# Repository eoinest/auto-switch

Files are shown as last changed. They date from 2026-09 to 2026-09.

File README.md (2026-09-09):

# auto-switch

A small Wi-Fi actuator that presses an existing **Decora-style paddle light switch**, using one MG90S servo and a 3D-printed mount.

The current POC uses a **headerless ESP32-S2 Mini** running MicroPython. It hosts a minimal website with **On**, **Off**, and **Recalibrate** buttons. Center calibration uses small movement controls and saves with **Done**. Open **http://auto-switch.local/** from a phone on the same Wi-Fi. The Mac is only needed for programming; it does not host the switch website.

## What works today

The USB-powered S2 joins Wi-Fi and serves the website directly. Both buttons render on a phone. Servo movement is still disabled pending wiring and calibration.

| Part of the POC | Status |
|---|---|
| ESP32-hosted website and local hostname | Tested on the board and phone |
| One MG90S servo operating the bedroom switch | Wiring, calibration and physical operation pending |
| Four AA batteries with a 5 V buck-boost converter | Selected; battery circuit and runtime untested |
| Printed servo mount and paddle | STL exported; physical fit and attachment unverified |
| Separate electronics holder | Screw mounts and retaining jaws modeled; converter measurements and dry fit pending |

## Build this version

**[Download the USB setup app for Mac](https://github.com/eoinest/auto-switch/releases/tag/companion-v0.1.0)** — Apple Silicon, macOS 15+, preview build. Python and USB tools included.

1. **[Parts list](BOM.md)** — selected components and what is already available.
2. **[Solder pads and wiring](docs/solder-prep.md)** — three S2 pads, four converter terminal groups and one servo. [Latest three-critic sanity check](docs/reviews/wiring-decision-2026-09-08.md); [detailed breadboard map](docs/s2-aa-poc.md).
3. **[Firmware](docs/s2-firmware.md)** — install MicroPython files, enter Wi-Fi credentials privately and open the phone page.
   **[Wireless updates](docs/wireless-updates.md)** — hold BOOT/0 for browser updates on home Wi-Fi; no recovery access point. [USB setup companion](docs/usb-wifi-setup.md) saves Wi-Fi credentials. Board verification pending.
4. **[Servo mechanism](docs/servo-command-mount.md)** — approved export, stock horn and two narrow Command-strip mounting pads.
5. **[Electronics holder](docs/electronics-retention.md)** — mounting-hole fastenings, converter clamps and removable battery retention under review.

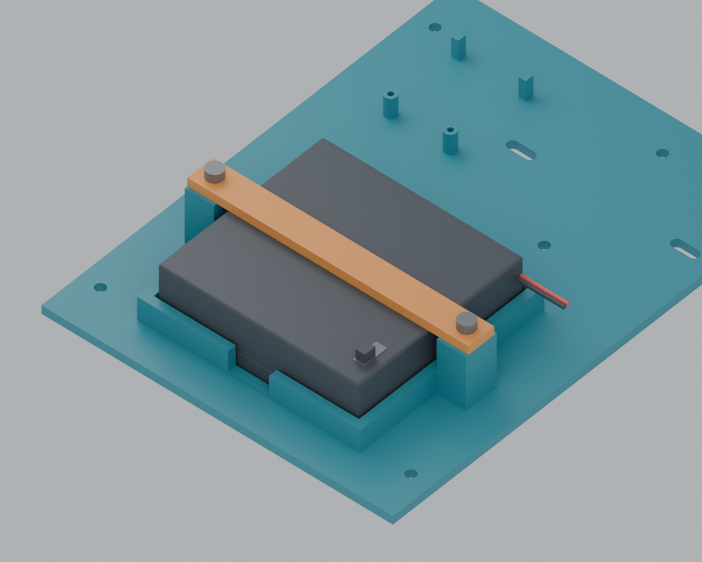
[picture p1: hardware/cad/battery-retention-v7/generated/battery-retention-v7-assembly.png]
Revised carrier with two centered battery towers and one flat bar


*The [v7 carrier and crossbar](hardware/cad/battery-retention-v7/README.md) use two centered towers level with the nominal battery case, with zero designed vertical gap. Reprint the carrier and bar; reuse the separate wall bracket. Physical fit is pending. The [converter clip audit](hardware/cad/battery-retention-v6/booster-fit-audit.md) identifies the unverified board thickness and dimensions.*

**Latest combined replacement print:** [V8 fit-test STL and instructions](hardware/cad/revision-print-v8/README.md) includes the revised battery carrier/bar and selected option C booster mount. Booster dimensions remain provisional; reuse the existing wall bracket.

## Double and triple switch concepts

[Multi-switch CAD](hardware/cad/servo-multi/README.md) extends the confirmed single-switch baseline with one servo per rocker, separate screw-on servo saddles, and two outer Command-strip pads. Each variant includes a Blender assembly and a master STL with the detached printed parts arranged on an A1 bed. The triple raises its center servo to clear its neighbor. These new mechanisms need physical motion testing; multi-servo electronics and firmware are separate future work.

## Power and control

Today, USB powers the ESP32. The planned portable version uses the holder's switch and a buck-boost converter to supply regulated **5 V to both the S2's VBUS pad and the servo**, with a shared ground. GPIO16 supplies the servo control signal.

The POC stays connected to Wi-Fi. It has no Daily/check-in selector, servo power gate or battery-level display. Each On/Off command briefly presses the requested end and returns to the calibrated neutral position so the rocker can be used by hand. Repeated commands still press; without a switch-position sensor, reported state stays unknown. Servo PWM stopping does not disconnect servo power.

For USB setup, open the dedicated booster-to-VBUS isolation switch, turn the battery holder off and unplug the servo connector; see the [USB setup and wiring map](docs/usb-wifi-setup.md). Before enabling movement, verify the converter output and calibrate the servo away from the wall switch. Keep private Wi-Fi configuration out of Git: [credential handling](docs/private-configuration.md).

## Project files

```text
firmware/                         MicroPython code and minimal switch website
hardware/cad/servo-command/        Isolated single-servo mechanism
hardware/cad/servo-multi/          Double/triple mechanical concepts and master STLs
hardware/cad/electronics-retention-v4/  Flat carrier, screw-on wall bracket and master STL
hardware/cad/battery-retention-v5/ Replacement battery rails, pressure pads and shims
hardware/cad/battery-retention-v6/ Archived upper-bar preview and booster clip fit audit
hardware/cad/battery-retention-v7/ Current carrier: two centered towers and one flat bar
hardware/wiring/s2-aa-poc/         Current bench wiring diagram
learn/s2-aa-poc.html               Interactive wiring viewer
```

See the [documentation index](docs/README.md) for source audits, development checks and historical designs. Earlier Pico, Mac gateway and battery-saving work remains in the repository as reference; it is not the current build guide.

Project-authored code, docs and original CAD use the [MIT license](LICENSE). Third-party reference CAD retains its [vendor terms](hardware/components/vendor/NOTICE.md).

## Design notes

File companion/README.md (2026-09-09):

# USB Wi-Fi setup

## Downloadable Mac app

[Download Auto Switch Setup 0.1.0](https://github.com/eoinest/auto-switch/releases/tag/companion-v0.1.0).
Unzip and double-click **Auto Switch Setup.app** (optionally drag it to Applications).
It opens the setup page in your default browser. Python and USB tools are included;
no terminal commands or dependency installation are needed. Use **Quit setup app**
on the page when finished. The app picks a free local port automatically.

This preview supports **Apple Silicon Macs, macOS 15 or later**. It is ad-hoc signed,
not Apple-notarized; macOS may block the first launch on a recipient's computer.
See [Apple's guidance on opening downloaded apps](https://support.apple.com/en-us/102445).
Do not disable system-wide security protections. Intel Macs and Windows are not
included in this release. Saving to a physical ESP32 still needs hardware testing.

The packaged app keeps temporary device settings under
`~/Library/Application Support/Auto Switch Setup/private/`, outside the app bundle,
with owner-only permissions, and deletes them after each setup attempt. The ZIP
contains no Wi-Fi passwords or device configuration. Firmware installation still
uses the project tooling; this companion only saves Wi-Fi on an already-configured board.

## Run from source

From the repository root:

```sh
python3 companion/server.py
```

Open **http://127.0.0.1:8790/** on this Mac. The companion uses the repository’s `.venv/bin/mpremote` when present, otherwise `python3 -m mpremote` (install with `python3 -m pip install mpremote`). Use `--port 8791` if needed. Stop with Ctrl-C.

Before connecting USB, turn **battery power OFF** and the **dedicated booster → ESP32 VBUS isolation switch OFF**, or physically disconnect that VBUS wire. Also unplug the servo’s three-wire connector; its control signal otherwise remains connected to an unpowered servo. Battery OFF alone leaves a possible USB backfeed path. Connect the already-provisioned S2 Mini using a USB data cable, select its port, enter the Wi-Fi network and password, and save. This does not install firmware. The device must already have a valid `config.json`. When finished, unplug USB first, then reconnect the servo and restore the battery circuit.

The companion reads the device configuration first, changes only `wifi.ssid` and `wifi.password`, uploads a temporary configuration, then renames it over `config.json` and restarts the board. Existing calibration and other configuration are preserved. Failed reads never create replacement defaults. If restart cannot be confirmed after saving, the page tells you to press RST.

The web server binds only to `127.0.0.1`. Host, Origin and random CSRF checks protect writes; credentials travel in the POST body, never URLs or process arguments. There are no HTTP access logs. Device-command output is captured and never displayed. Temporary configuration files live under ignored `.local/s2/` with owner-only directory/file permissions and are deleted after each attempt. A forced process kill or computer crash can leave a private temporary directory there; it remains ignored by Git. Close the page and stop the companion when finished.

Select a 2.4 GHz personal Wi-Fi network supported by the S2 Mini. Passwords must contain 8–63 printable ASCII characters. After restart, join that Wi-Fi on your phone and open `http://auto-switch.local/` or the device’s address. There is no fallback access point or Wi-Fi editor on the device in this workflow.

## Build the Mac app

On an Apple Silicon Mac with Python 3.14 (this release was built on macOS 15.7.4):

```sh
python3 -m venv /tmp/auto-switch-build
/tmp/auto-switch-build/bin/python -m pip install -r companion/packaging/requirements.txt
/tmp/auto-switch-build/bin/python companion/packaging/build_macos.py
python3 companion/packaging/verify_macos.py
```

The shareable ZIP and `SHA256SUMS.txt` appear under `dist/companion/`. The verifier
extracts the ZIP to a path with spaces, checks its signature/architecture and
private-file inventory, runs the bundled USB helper on a minimal PATH, then tests
the HTTP assets, port enumeration and authenticated Quit action. It does not write
to USB hardware. Build inputs explicitly include UI assets and dependency metadata,
not the repository's private configuration directories. Dependency licenses are
included in the application resources.

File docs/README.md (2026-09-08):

# Documentation

Start with the [project overview](../README.md). The current POC is one headerless ESP32-S2 Mini, one MG90S servo, and a planned four-AA/5 V buck-boost supply. The ESP32 hosts the On/Off website directly.

## Current build

| Guide | Use it for |
|---|---|
| [Parts list](../BOM.md) | Current components and purchase links |
| [S2 wiring](s2-aa-poc.md) | Breadboard connections and power checks |
| [S2 firmware](s2-firmware.md) | Wi-Fi setup, board-hosted website and updating files |
| [USB Wi-Fi companion and isolation switch](usb-wifi-setup.md) | Save credentials over USB and wire the dedicated VBUS switch |
| [Home Wi-Fi updates](wireless-updates.md) | Upload application bundles after connecting to home Wi-Fi |
| [Servo mechanism](servo-command-mount.md) | Mount, paddle and approved STL exports |
| [Electronics mounting](electronics-retention.md) | Screw mounts, converter jaws and removable battery retention; design review |
| [Previous carrier fit tests](electronics-carrier-v2.md) | Earlier v2 tray and small interface tests |
| [Private configuration](private-configuration.md) | Keep credentials out of Git |

## Mechanical extensions

- [Double and triple switch mechanisms](../hardware/cad/servo-multi/README.md): Blender assemblies, master STLs, dimensions and independent checks. The operating POC remains one servo.

## Supporting detail

- [Electronics component/source audit](s2-electronics-component-audit.md)
- [Independent carrier STL checks](../hardware/cad/electronics-carrier-v2/generated/independent-verification.json)
- [Detailed current BOM CSV](../hardware/s2-current-bom.csv)
- [Interactive S2 wiring viewer](../learn/s2-aa-poc.html)

The HTML viewer can be served locally with `python3 -m http.server 8767 --directory learn`, then opened at `http://localhost:8767/s2-aa-poc.html`. This is a documentation viewer, separate from the ESP32-hosted control website. Its illustration is a bench wiring reference; the v2 CAD guide is the current mechanical reference.

## Development checks

From the repository root:

```sh
python3 -m unittest discover -s tests -p 'test_firmware*.py'
node --check firmware/www/app.js
python3 hardware/cad/electronics-carrier-v2/verify_independent.py
```

These check software logic and exported meshes. They cannot establish servo calibration, component fit or battery runtime.

## Historical designs

Earlier designs remain at their existing paths so old links still work. They are not required for the current POC:

- [Pico / gated-power BOM](history/pico-bom.md)
- [Pico power design](power.md) and [wiring](wiring.md)
- [Mac gateway](gateway.md) and [earlier firmware guide](firmware.md)
- [Previous S2 electronics tray](s2-aa-mechanical.md), superseded by v2
- [Earlier AA/Pico demo](aa-demo-plan.md)
- [Circuit learning material](../learn/README.md), which includes earlier designs

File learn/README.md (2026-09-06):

# Learn the Auto Switch circuit

**Earlier Pico circuit course — educational reference, not the current POC wiring.** Use the [current S2 illustrated map](s2-aa-poc.html), [S2 wiring guide](../docs/s2-aa-poc.md) and [current BOM](../BOM.md) for this build.

Open `index.html` directly in a browser, or serve this folder locally from the repository root:

```sh
python3 -m http.server 8766 --bind 127.0.0.1 --directory learn
```

Then visit **http://127.0.0.1:8766**. There is no package installation, account, CDN, analytics, or connection to a real Pico. The learning module never sends device commands. External reference and purchase links need internet access, but the bundled lessons, experiments, diagrams and BOM work offline. Progress is stored in this browser when local storage is available; file-URL storage behavior varies by browser.

## Suggested path

1. Start with **Connection map** to see the entire circuit. Use **Fit entire map**, zoom, or **Full screen**. Then in **Power explorer**, compare Battery, USB and Both. Turn the battery master off while USB remains plugged in. Predict why the Pico is awake but the servo rail stays off.
2. Follow the **12 guided lessons** in order. Work the example before looking at its answer, then answer both questions. Explanations remain available after a wrong answer, and you can retry.
3. Use the **Workbench** to vary resistance, design a battery voltage divider, inspect pulse timing, explore capacitor droop and estimate energy. Each experiment names its assumptions and source references.
4. Complete **Design it yourself**. Its eight checks and six-step open design brief ask you to choose the connections and explain why they work.
5. In **Parts & fit**, choose one or two switches. Search the complete BOM, inspect each STL mapping, and read the fit evidence before buying or printing.

The **Breadboard** tab adds a matching bench layout for the existing headered Pico: choose one or two servos, highlight a build step, and follow the component/jumper table. The downloadable guide includes bench-only purchases and first-power checks.

## Sources and limits

The curriculum and claim-level source registry are in [`docs/learn-content.json`](../docs/learn-content.json) and [`docs/learn-sources.md`](../docs/learn-sources.md). Core references are manufacturer documentation from Raspberry Pi, Pololu, Panasonic, SCHURTER, SparkFun and Adafruit, plus MicroPython documentation. Project-specific firmware behavior is labeled as a project claim, not independent manufacturer evidence.

The power map illustrates nominal steady states and source availability. It does not calculate transient behavior, exact diode drops or current sharing. The battery calculator uses explicit assumptions, not measured runtime. The fit report separates digital geometry checks from unverified physical parts and mounting. The selected board is a headerless Pico W; a different board or horn needs its own fit check.

## Rebuild and verify

The site bundles source material so `file://` use does not depend on network fetches. Edit the source curriculum, hardware diagrams or BOM, then rebuild:

```sh
python3 tools/render_wiring.py
python3 tools/build_learning.py
python3 tools/build_learning.py --check
node tests/test_learning_model.cjs
python3 -m unittest discover -s tests -v
```

`build_learning.py` includes source hashes and copies only the public educational assets into `learn/assets`. Serve this folder, not the repository root containing development configuration. The generated `data.js` should not be edited by hand.

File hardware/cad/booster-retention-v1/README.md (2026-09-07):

# XL63070 end-finger mount — FIT-TEST v1

This is a **printable fit test**, based on an unmeasured **16 × 30 × 1.2 mm PCB assumption**. It replaces the oversized converter floor and side jaws, using the same carrier holes at X22/Y22 and X22/Y68 (46 mm pitch). The carrier does not need to be reprinted for this adapter alone.

- [All five booster pieces in one STL](generated/booster-retention-v1-ALL-FIVE-FIT-TEST.stl)
- [Assembly](generated/booster-retention-v1-assembly-FIT-TEST.png)
- [Print layout](generated/booster-retention-v1-print-layout-FIT-TEST.png)
- [Dimensions and validation manifest](generated/manifest.json)
- Individual pieces are in `generated/stl-fit-test/`; corresponding Blender scenes are in `generated/`.

## Parts and hardware

| Piece | Quantity | Size, mm |
|---|---:|---|
| Open adapter with low guides and end supports | 1 | 20 × 58 × 6.2 |
| Removable end finger | 2 | 8.2 × 13.6 × 2 |
| Seat-height shim | 2 | 7.8 × 11 × 0.4 |

Use **two M3×16 screws and two ordinary M3 nuts** from the existing assortment. Each screw passes through a finger, its shim, the adapter and the carrier. The two **0.4 mm shims are essential for the default modeled stack**; they place the finger undersides at the assumed PCB top, Z7.7. The hard seats beneath them prevent indefinite downward travel. The screw under-head plane is Z9.7 and its tip is Z−6.3, with full engagement through the nut at Z0…−2.4. This leaves 3.7 mm to the existing wall-bracket pad-front plane at Z−10; check the actual screw stack when assembling.

## Print and dry fit

Print at **100% scale, millimeters**, with all pieces flat as exported. The nominal geometry needs no supports. A 0.2 mm layer height makes each shim two layers thick; verify those layers in the slicer before printing. The two fingers and two shims are identical pairs; their upper/lower names identify assembly positions.

1. With power disconnected, remove the old converter floor and jaws. Place the new adapter over the existing pair of mounting holes.
2. Set the board on the support shelves. Its solder joints, underside parts and four corner pads must clear the plastic. The two narrow end-center support shelves are assumed bare locations, not physically verified.
3. Put one 0.4 mm shim on each raised screw seat, then one finger above it with the narrow tongue facing the PCB. The side keys prevent the finger twisting.
4. Start with each screw centered in its slot. At the nominal position each 2.8 mm-wide tongue overlaps the center of the PCB end by 0.6 mm. The 1.6 mm-deep underside shelf supports the tongue footprint including inward adjustment. Outward movement can lose capture; check that both tongues actually overlap the board and remain between the terminal pads.
5. Install the nuts and tighten gently against the seats. Do not bend the PCB or force a finger over a component. If the board thickness or contact areas differ, stop and revise the fit instead of tightening harder. Route and secure wires separately so solder joints do not carry cable pull.

The underside support height is Z6.5, the assumed PCB top is Z7.7, and the low end stops finish at Z7.22 so they do not defeat subsequent shim-height changes. Low side guides touch the substrate edge rather than covering its populated top. The central underside and terminal corners remain open.

The board envelope, thickness, underside clearances and contact patches still need a physical check. This export is not a claim of production fit or thermal validation. Existing battery, controller and wall-bracket models are unchanged.

```sh
/Applications/Blender.app/Contents/MacOS/Blender -b --factory-startup --python hardware/cad/booster-retention-v1/generate.py
```

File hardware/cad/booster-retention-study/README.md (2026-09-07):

# Compact XL63070 mount study

This is a **visual comparison, not a printable design**. The received board is much smaller than the former 40 × 36 mm placeholder. These scenes use a provisional **16 × 30 mm PCB**, with **1.2 mm thickness assumed**. Component boxes are reconstructed approximately from the user's photos; underside parts, solder joints, bare contact areas and exact dimensions remain unverified.

- [Three options](generated/booster-retention-options-PROVISIONAL.png)
- [Recommended candidate closeup](generated/recommended-end-fingers-PROVISIONAL.png)
- [Editable Blender scene](generated/booster-retention-options-PROVISIONAL.blend)
- [Independent design review](design-review.md)

| Option | Retention | Tradeoff |
|---|---|---|
| A: slide-in rails | Continuous top lips and a removable end stop | Lips approach the inductor and right-edge components; removal requires sliding the wired board. |
| B: split side clamps | Short adjustable side jaws | Less coverage, but the proposed long-edge contact patches are crowded and unverified. Additional adapter hardware is needed. |
| **C: narrow end fingers** | Two keyed, removable fingers over the center of each short end; low side guides | Best candidate from the photos: the corner solder pads stay open. The narrow center contact patches and underside supports still need confirmation. |

**C is recommended for the next fit prototype.** Orange pieces are removable retaining fingers. Gold pieces represent thin seat-height shims. Teal shoulders beneath them provide a hard screw stop; tightening is not intended to force a poorly matched clamp onto the PCB. Measured board thickness sets the shoulder height, with small shim changes available for printed fit. Each finger is 2.8 mm wide and overlaps the board by only 0.6 mm in this concept. Low guides touch the substrate edge below its populated top face. Separate small end stops sit between the corner pads and leave 0.2 mm nominal end clearance. The central underside is open, and support ledges avoid the terminal-pad regions.

The adapter reuses the **46 mm spacing** between the existing converter-floor mounting holes. On the actual carrier these are X22/Y22 and X22/Y68. The study spreads the three candidates sideways for comparison; those scene positions are not assembly coordinates. Replace the old converter floor and jaws, while retaining the current carrier. Schematic screw heads in these images indicate attachment locations; no shafts or screw lengths are modeled. Final length and stack will follow actual measurements. Add wire strain relief away from solder joints.

No STL is generated. Before a fit coupon or final mount: confirm PCB width, length and thickness; show the underside; verify the two narrow bare center patches and support zones; account for the soldered wires. See the root-owned requirements and fit-evidence notes for measurement provenance.

```sh
/Applications/Blender.app/Contents/MacOS/Blender -b --factory-startup --python hardware/cad/booster-retention-study/generate.py
```

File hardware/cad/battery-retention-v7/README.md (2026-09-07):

# V7: two centered towers and one flat bar

This revision **reprints the carrier**. All four old battery towers and their holes are removed. Only two towers remain, centered beside the holder at X ±43 mm, Y −32 mm. Existing S2, converter and wall-bracket attachment geometry stays in place.

The seller lists the battery case body as **19 mm thick**; its switch protrudes another 3.5 mm. The case sits on the 3 mm base. Both new tower tops and the flat bar underside are therefore **Z22 mm**, with **zero designed vertical clearance**. The bar rests directly on the nominal case and towers. Actual molded dimensions and printing tolerances still need a dry fit; do not force a thicker case under the bar.

- [Combined new carrier and bar STL](generated/battery-retention-v7-NEW-CARRIER-AND-BAR.stl)
- [Carrier alone](generated/01_NEW-CARRIER-v7.stl)
- [Flat bar alone](generated/02_FLAT-CROSSBAR-v7.stl)
- [Assembly](generated/battery-retention-v7-assembly.png)
- [Print layout](generated/battery-retention-v7-print-layout.png)

Both pieces are flat on the bed in the exports, in millimeters. The carrier is 120 × 160 × 22 mm; the bar is 96 × 10 × 3 mm. The combined layout fits a 256 × 256 mm A1 bed. It includes only these two revised pieces; reuse the separate wall bracket. The converter retainers still require verification against the actual board before reuse.

Use **two M3×30 screws and two ordinary M3 nuts** for the battery bar. Your WEIDEER kit B0DS8HYF64 includes M3×30 screws, so no additional fastener order is needed ([seller assortment chart](https://m.media-amazon.com/images/I/71Ddx5vNT7L._SL1500_.jpg)). The screw head bears at Z25 and its tip ends at Z−5, below the nut but ahead of the wall-bracket pad. The previous M3×35 screws are too long for this shorter stack. Remove the bar to lift out the battery holder. Switch and upper-right cable access remain open. The original cradle's horizontal clearance remains; existing V5 shims are optional for lateral play.

`config.json` drives case thickness, both tower heights and the bar position together. The generator checks closed connected printable meshes and absence of all four old posts. Independent review files record saved-mesh checks. This revision does not establish the fit of the previously modeled converter placeholder.

```sh
/Applications/Blender.app/Contents/MacOS/Blender -b --factory-startup --python hardware/cad/battery-retention-v7/generate.py
```

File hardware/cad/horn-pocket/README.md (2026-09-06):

# Recessed stock-horn locating seat — provisional

This revision adds a shallow shaped seat so the supplied servo horn can locate against the paddle before its screws are installed. The printed rim guides alignment; **the screws still retain the horn**. Nothing replaces the supplied spline or center screw.

The supplied photo identifies a **straight, tapered double-ended horn with rounded tips**. Its outline is now photo-estimated as **31.5 mm overall span, 5.3 mm arm root width, 4.0 mm tip width and 7.4 mm hub diameter**. The printed frame underneath provides the approximate scale. Perspective and horn height make this an estimate, not a precision measurement: independent estimates span approximately 31–32 mm, with about ±1 mm overall uncertainty. Arm thickness **2 mm** and hub depth **4 mm** remain unmeasured assumptions. See [source notes](sources.md).

## What is ready

- [Blender close-up](generated/horn-seat-closeup-PROVISIONAL.blend) and [render](generated/horn-seat-closeup.png): empty seat, seated horn, and lifted horn.
- [Paddle-family Blender preview](generated/paddle-family-pocket-PREVIEW.blend) and [render](generated/paddle-family-pocket.png): the interface in the normal, mirrored and raised-center paddles. **Preview only; no production paddle STLs exported.**
- [All three fit coupons STL](generated/horn-fit-coupons-ALL-THREE-PHOTO-ESTIMATE.stl): three small flange-only samples using **97%, 100% and 103% profile sizes**, each with **0.3 mm clearance per side**. Their underlying horn spans are 30.555, 31.5 and 32.445 mm.
- Three corresponding individual coupon STLs and `horn-fit-coupons-print-layout.png` identify their order. Labels are display-only, not embossed on the prints. The supplied layout runs 97%, 100%, 103% along increasing X. Mark them before removing them from the bed. Import the complete file at 100% scale; the three profile sizes are already built into it.

Print the coupon cavity facing up, flat floor on the bed. These coupons only test the assumed horn interface; they do not attach to the wall or actuate a switch. Try the actual horn in each coupon without forcing it. Choose a pocket that seats flat with minimal play, then report its label and whether the screw holes line up. None may fit if the photo or unmeasured underside geometry differs substantially; adjust the model from that result before printing a full paddle.

## Geometry

The existing horn/paddle contact plane remains **X = 13 mm**. Adding a **1.2 mm-high rim** toward the servo creates the recess without moving the horn along its shaft. The original **4 mm flange floor** remains intact. At the nominal 100% profile and default 0.3 mm clearance, the pocket is a **32.1 mm overall tapered/rounded arm outline and 8.0 mm hub circle**, surrounded by **1.2 mm walls**. The flange is widened to **36 mm**, supporting even the largest coupon's 35.445 mm outer rim span. A single closed polygon merges the tapered arms, round tips and hub; no rectangular substitute is used.

The assumed 2 mm-thick arm would remain 0.8 mm proud of the rim; actual arm thickness still needs checking. A **4.8 mm center opening** preserves tool access, and the two original adjustable attachment slots remain centered at Y = ±7 mm. Their overall length is 6.2 mm: 4 mm straight section plus 2.2 mm diameter round ends. Actual horn fastener diameter remains unconfirmed.

The full-paddle preview includes a 45-degree transition from X−3/Y±6 to X9/Y±18, supporting the widened flange from the existing paddle beam. Before a production export, we still need to verify the actual horn outline, seating face, screw fit, tool clearance and complete mechanism travel with the new rim.

## Checks

The generator requires all coupon and preview paddle meshes to be watertight, one connected component and positive volume. Coupon orientation is floor-down, cavity-up. Geometry checks do not establish a physical fit. `validation.json` records dimensions, source hash and remaining assumptions.

The [independent interface review](independent-review.md) verifies the nominal seated horn, floor depth and screw paths. `python3 hardware/cad/horn-pocket/verify_stl_independent.py` independently checks the exported coupon meshes, master equivalence, spacing and bed placement.

Existing single-switch and double/triple production files were not changed.

```sh
/Applications/Blender.app/Contents/MacOS/Blender -b --factory-startup --python hardware/cad/horn-pocket/generate.py
```

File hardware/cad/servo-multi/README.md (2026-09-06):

# Double and triple switch actuators

These mechanical concepts extend the user-confirmed single-switch fit to nominal **46 mm gang centers**. They leave the original single model unchanged. Actual double/triple plate fit, travel and adhesive capacity have not been tested.

Each rocker has its own MG90S. The double mount points both servos outward. The triple points the outer servos outward and raises the center servo axis by 30 mm, avoiding the adjacent paddle. Its longer center contact legs have closer-spaced tips so they stay over the intended rocker during the modeled motion.

## Files

Each `generated/double/` and `generated/triple/` directory contains:

- `double-ALL-PIECES-CONCEPT.stl` or `triple-ALL-PIECES-CONCEPT.stl`: all separate printable parts on one A1 bed, in millimetres.
- Numbered individual STLs, retaining the same print-layout XY positions.
- `*-assembled-CONCEPT.blend`: installed arrangement, with reference-only plate, servos, stock horns and soft pads.
- `*-print-layout-CONCEPT.blend` and `print-layout.png`: print orientations.
- `assembly.png`, `validation.json`, and `independent-stl-audit.json`.

See the [independent review](independent-review.md) and [dimension sources](sources.md) for the checks and their limits.

The double set has **five printed pieces**: frame, two screw-on saddles and two paddles. Triple has **seven**: frame, three saddles and three paddles. These are separate objects in the master STL, not print-in-place assemblies.

## Horn alignment revision

A [recessed horn-seat prototype](../horn-pocket/README.md) is being developed to locate the stock horn before fastening. It now models the photographed tapered horn and includes three fit coupons bracketing the photo-derived size estimate. Physical fit and thickness remain unverified. The master STLs above retain the reviewed flat horn interface.

## Attachment and printing

The frame has two uninterrupted **14.5 × 116 mm rear landing pads**, one at each outside edge. Each accepts one mating pair of Command 17207 narrow strips. There are no inter-gang adhesive pads: the approximately 11 mm gap between assumed bezels is too narrow for the full strip outline. The centered strips sit behind the frame. To remove wall-side strips, first separate the interlocking pairs and lift away the frame, then stretch-release each wall-side tab according to the manufacturer instructions; do not glue the two halves together. Plastic projects 0.85 mm past each top/bottom edge of the nominal plate, while the centered 92.74 mm strip outline stays on the plate. Mated strip thickness remains an assumed 4 mm.

The frame prints with its entire rear face on the bed. Servo saddles print separately, foot down, and bolt to the frame after printing. The paddles print broad side down and include a 45-degree transition beneath the horn flange. Saddle ear holes are horizontal 2.2 mm bores with short bridges; inspect the slicer preview before printing. No tall chassis overhang is needed. The original single-switch paddle file has not been modified.

Saddle screws sit at **Y = ±54 mm**, beyond the entire strip outline. Their heads are on the front of the saddle, and ordinary nuts go behind the frame. Assemble and tighten these before attaching strips. The nominal stack is 4 mm saddle + 3 mm frame + 2.4 mm nut. An M3×10 screw extends approximately 0.6 mm beyond the nut and stops 1 mm above the nominal plate face. Omit washers for this length; verify actual screw/nut and strip thickness before sticking the frame down.

| Item | Double | Triple |
|---|---:|---:|
| MG90S, with original horn and center screw | 2 | 3 |
| M3×10 saddle screws | 4 | 6 |
| Ordinary M3 nuts | 4 | 6 |
| M2×10 servo-ear screws | 4 | 6 |
| Ordinary M2 nuts | 4 | 6 |
| Command 17207 mating pairs | 2 | 2 |
| Soft contact pads, 7.9 mm diameter × 2.2 mm | 4 | 6 |

Horn-to-paddle fasteners still depend on the supplied horn's actual holes; the model retains the single design's adjustable two-hole arrangement. Do not substitute a printed spline for the stock horn.

## Verification limits

The generator checks each paddle against the frame, all saddles and servo envelopes at every integer angle from −10° through +10°. It also checks all independent combinations of paddle angles, rather than rotating every channel together. All printable parts must be watertight, one connected component each, positive volume and packed within the A1 bed. These checks do not prove adhesive peel strength, actual switch travel, servo force or printed stiffness.

The original outer contact geometry is retained: axis Z31, contacts Y±26, soft-pad bottom Z13.7. Its nominal circular-pad edge only barely fits the assumed 65 mm rocker at the worst sampled angle. This needs a real multi-plate travel check despite the single fit confirmation. The triple center changes to axis Z61, contacts Y±19, soft-pad bottom Z12; this keeps its complete soft-pad contact footprint inside the modeled rocker while reaching approximately the same press depth as the outer mechanism. Long center legs and posts need physical stiffness testing.

These models do not change the one-servo firmware or certify the existing battery/converter for two or three simultaneous servo loads. Multi-channel controls and power sizing are separate work.

## Regenerate

```sh
/Applications/Blender.app/Contents/MacOS/Blender -b --factory-startup --python hardware/cad/servo-multi/generate.py -- double
/Applications/Blender.app/Contents/MacOS/Blender -b --factory-startup --python hardware/cad/servo-multi/generate.py -- triple
```

Run `python3 hardware/cad/servo-multi/verify_stl_independent.py` to independently check the exported files against the master layouts.

The generator only replaces its own variant exports. `config.json` records nominal plate dimensions and the source single-config path. `validation.json` records the source hash.

Plate references: [Leviton wallplate size guide](https://leviton.com/content/dam/leviton/commercial-industrial/product_documents/solution_sheets/Wallplate%20Size%20Guide%20Q-1289.pdf), [Leviton dimensional drawing](https://leviton.com/content/dam/leviton/residential/product_documents/product_specification/Q-874A%20Special%20Purpose%20Wallplates%20PB.pdf). Strip reference and original MG90S envelopes remain in `../servo-command/config.json`.

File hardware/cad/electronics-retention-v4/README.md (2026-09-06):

# V4: flat carrier and separate Command-strip bracket

This revision separates the mounting structure into two printed pieces: the flat-bottom electronics carrier and one H-shaped wall bracket. The four integrated v3 feet are removed. Existing battery bars, converter floor, and converter jaws are preserved, so the complete print contains **seven pieces**.

Use [`generated/electronics-wall-mount-ALL-PIECES-v4-CONCEPT.stl`](generated/electronics-wall-mount-ALL-PIECES-v4-CONCEPT.stl) for printing. All seven pieces are oriented on Z=0 and spaced within a 245 × 228 mm footprint on the A1's 256 × 256 mm bed. This leaves 5 mm at the closest bed edges; adjacent part envelopes have a minimum 5 mm gap, so use no more than a 2 mm brim in this layout and inspect slicer placement. The assembled STL is for assembly visualization, not print-in-place.

## Wall attachment

- Two continuous rear pad faces, **20 × 144 mm each**, accept one mating pair of narrow Command 17207 strips per pad. The previously recorded strip outline is 12.65 × 92.74 mm. The long pads leave room to position the removal tabs at the lower edge.
- Carrier underside is Z=0; bracket rear adhesive face is Z=-13 mm. Pads are 3 mm thick, and four standoffs rise 10 mm from their front faces.
- Four attachment centers are X=±53, Y=±65 mm, clear of the existing component fasteners.
- Use **four M3 × 12 mm machine screws and four ordinary M3 nuts**, without washers. Screws enter from the carrier front through 3.4 mm clearance holes.
- Insert nuts into the inward-facing side slots before fitting the carrier. The 6 mm-wide slots constrain ordinary 5.5 mm-across-flats M3 nuts against rotation. Slot height is 2.8 mm; the nominal nut is 2.4 mm thick.
- The screw clamps the carrier and the 4.6 mm-thick roof above each nut. A 12 mm screw ends at Z=-9, inside the blind standoff bore, leaving 4 mm before the rear adhesive plane. The deepest existing component screw ends at Z=-6, leaving 4 mm to the bracket's pad fronts and 7 mm to its rear plane.
- Remove the carrier before removing Command strips so the stretch-release tabs are accessible. Pull according to the strip manufacturer's instructions along the wall, not outward. No adhesive thickness or published strip weight rating is treated as a guarantee against servo force or peeling.

## Electronics assembly fasteners

| Fastener | Quantity | Use |
|---|---:|---|
| M1.6 × 16 mm screws | 2 | S2 mounting holes and standoffs |
| M1.6 nuts | 2 | S2 mounting screws |
| M3 × 35 mm screws | 4 | Battery retaining bars |
| M3 × 10 mm screws | 4 | Converter floor and jaws |
| M3 × 12 mm screws | 4 | New carrier-to-wall-bracket attachment |
| M3 nuts | 12 | Eight component screws and four bracket screws |

No washers are included in these stacks. Servo mechanism fasteners are separate.

## Printing

The carrier's entire 120 × 160 mm underside lies on the bed; no supports are needed under a suspended base floor. The bracket prints with both adhesive pad faces directly on the bed. Its nut-pocket roofs require approximately **6 mm bridges**; inspect bridging in the slicer rather than enabling support inside nut cavities. Existing converter jaws lie on their sides and retain a 1 mm recess that may need local support; this revision does not claim every retained component is entirely free of support requirements.

Keep adhesion faces flat. Dry-fit screws, nuts, and purchased components before loading the wall mount. Component fit remains a concept: the converter's 40 × 36 mm envelope is still an unmeasured placeholder, and actual PCB edge clearances, holder protrusions, and S2 underside solder joints need physical checking.

## Files and regeneration

- `generated/electronics-print-layout-v4.blend`: seven printed pieces, laid out for the A1.
- `generated/electronics-retention-v4.blend`: assembly, including non-printable reference electronics and screws.
- `generated/stl-concept/`: individual printed pieces.
- `generated/export-manifest.json`: dimensions, placement transforms, STL hashes, and geometry checks.
- `generated/assembled-v4.png`, `rear-pads-v4.png`, `print-layout-v4.png`: visual reviews.

Run from the repo root:

```sh
/Applications/Blender.app/Contents/MacOS/Blender --background --factory-startup --python hardware/cad/electronics-retention-v4/generate.py
```

This generator produces only printed geometry in both STL exports. Hardware references never enter the print files. The original v3 files are preserved.

Run the independent binary-mesh and layout audit after generation:

```sh
python3 hardware/cad/electronics-retention-v4/verify_stl_independent.py hardware/cad/electronics-retention-v4/generated/stl-concept hardware/cad/electronics-retention-v4/generated/electronics-wall-mount-ALL-PIECES-v4-CONCEPT.stl
```

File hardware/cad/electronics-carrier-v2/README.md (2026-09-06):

# Electronics carrier v2 — fit-test draft

This separate revision preserves the existing edited CAD. It addresses confirmed geometry problems in the previous electronics tray; it is **not final physical fit approval**. The converter for Amazon B0GCW44FDL is not measured, so the pink reference is explicitly a reserved space, not an exact board model.

The carrier is 120 × 160 × 10 mm and exports flat at Z=0. The 3 mm floor, vertical rests, and open through-slots are intended for a straightforward bench fit print on the A1. All dimensions are millimetres. No wall mounting or adhesive attachment is claimed for this electronics tray.

Changes:

- USB-C faces outboard, away from the AA case, with a 12 × 20 × 10 mm illustrative plug keepout. The actual USB cable envelope remains unmeasured.
- All retention slots pass through the full printed geometry. S2/converter slots are 3.5 mm wide for nominal 2.5 mm ties. Battery slots are 4.5 mm wide; wide Velcro straps will not fit them.
- Every slot has at least 3 mm of material to the outer tray edge; the tightest is 3.25 mm. The former battery-slot edge sliver was only about 0.4 mm.
- The battery pocket allows 0.7 mm per side around the seller-nominal 68.7 × 64.2 mm case. Remove both retaining ties and lift the case out to operate its back switch or screw cover. No unverified switch position is modeled.
- The headerless S2 rests on four small outer-corner supports. The underside is 7 mm above the floor, reserving 3 mm for solder joints. The supports avoid the nominal pad rows, but an inspection of the actual board underside is still required. The straps must avoid components, buttons, antenna, and solder joints.
- The converter area has a continuous insulating floor and external slots. A small board cannot fall through an unsupported 37 mm rail gap. An **insulating spacer and actual strap path remain to be selected after inspecting the module underside**. Do not treat the bare flat floor as a finished converter mounting solution.

## Print the small checks first

1. `generated/holder_fit_ring.stl` checks the nominal battery case outline with its 0.7 mm side allowance. Check the actual case's widest seam, screw, wire outlet, and switch projection too.
2. `generated/s2_corner_support_coupon.stl` reproduces the corner support footprints and 7 mm underside clearance. Confirm the board sits on bare PCB areas without contacting components or solder joints. Check the actual soldered wire exits.
3. `generated/electronics_carrier_v2_DRAFT_FIT_TEST.stl` is the larger layout draft. Print only as a fit-test prototype until the converter and retention details are resolved.

For temporary battery retention, use two removable/releasable ties that fit the 4.5 mm slots, approximately 250 mm long, without squeezing the battery case. Other lengths and strap styles need a fit check. The seller specifies the switch on the back; normal service requires lifting the holder out.

## Generate and review

```sh
/Applications/Blender.app/Contents/MacOS/Blender -b --factory-startup --python hardware/cad/electronics-carrier-v2/generate.py
```

The generator checks finite positive dimensions, manifold connected positive-volume prints, slot edge ligaments, rays through every slot center, nominal battery/PCB envelope separation, and nominal corner-pad clearance. These checks do not establish real component fit, strength, printing tolerances, or safe component retention.

`generated/electronics-carrier-v2.blend` contains `ELECTRONICS_V2_ASSEMBLY` with origin at the carrier center and floor Z=0. Fit coupons and presentation objects have separate collections. The existing approved isolated servo mechanism is unchanged and is not generated here.

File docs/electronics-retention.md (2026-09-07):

# Electronics mounting — v4 carrier and battery-retainer revisions

**Current battery layout:** [v7 carrier and flat crossbar](../hardware/cad/battery-retention-v7/README.md) replaces the carrier. All four old battery towers are removed. Two new towers sit at the middle of the holder, with their tops and the flat bar underside level with the nominal 19 mm case body. There is **zero designed vertical gap**. Print the new carrier and bar; reuse the separate wall bracket. The battery bar now uses **two M3 × 30 mm screws and two ordinary M3 nuts**.

The [v6 upper-bar preview](../hardware/cad/battery-retention-v6/README.md) and [v5 adjustable retainers](../hardware/cad/battery-retention-v5/README.md) are historical alternatives. Optional v5 side shims can still address horizontal cradle play. The old seven-piece v4 master below is an archived export, not the current carrier/bar layout.

The original v4 mounting structure printed as **two pieces**: a carrier with a flat underside and a separate H-shaped wall bracket. Four screws join them after printing. The bracket has two continuous **20 × 144 mm** rear pads for the narrow Command strips. The five removable component retainers remain separate, making seven printed pieces total.

The mounting geometry has been checked; purchased-component fit and adhesive retention remain unverified. The received XL63070 converter is visibly too small for the earlier placeholder mount; its old clips failed physical fit. See the [replacement mount study](../hardware/cad/booster-retention-study/fit-evidence.md).

## Current files

Use the [V8 combined replacement fit-test STL](../hardware/cad/revision-print-v8/generated/auto-switch-ALL-NEW-PIECES-v8-FIT-TEST.stl) and [print/assembly instructions](../hardware/cad/revision-print-v8/README.md). It includes the V7 carrier/bar and five option C booster pieces. Reuse the separate wall bracket. The booster model assumes a 16 × 30 × 1.2 mm PCB; actual thickness and underside remain unmeasured. Physical fit is not approved.

## Archived v4 files

- **[Master STL: all seven pieces laid out for printing](../hardware/cad/electronics-retention-v4/generated/electronics-wall-mount-ALL-PIECES-v4-CONCEPT.stl)**
- [Blender print layout](../hardware/cad/electronics-retention-v4/generated/electronics-print-layout-v4.blend) · [assembled Blender model](../hardware/cad/electronics-retention-v4/generated/electronics-retention-v4.blend)
- [Rear adhesive pads](../hardware/cad/electronics-retention-v4/generated/rear-pads-v4.png) · [print layout image](../hardware/cad/electronics-retention-v4/generated/print-layout-v4.png)
- [Dimensioned mechanisms and fastener BOM](../hardware/cad/electronics-retention-v4/README.md)
- [Independent mounting review](../hardware/cad/electronics-retention-v4/independent-review.md) · [STL audit](../hardware/cad/electronics-retention-v4/generated/independent-stl-audit.json)

The master STL contains only printed pieces; electronic references and fasteners are excluded. Its **245 × 228 mm** footprint fits the A1's 256 mm bed, with at least 5 mm between part bounding boxes. Each part starts at Z=0. Import in millimetres, preserve the layout, and use **by-layer** printing. Check any brim or skirt stays inside the bed. The carrier has no underside feet or suspended floor; the bracket prints adhesive-side down. Its nut pockets have short 6 mm bridges. The existing converter jaws have small recessed faces that may need local support; inspect the slicer preview.

The [assembled STL](../hardware/cad/electronics-retention-v4/generated/electronics-wall-mount-ASSEMBLED-v4-CONCEPT.stl) is an assembly preview, not a print-in-place file. Individual STLs are in [stl-concept](../hardware/cad/electronics-retention-v4/generated/stl-concept/).

## Attach the wall bracket

Use **four M3 × 12 mm screws and four ordinary M3 nuts**, in addition to the component hardware. Slide the nuts into the bracket's inward-facing pockets before attaching the carrier. Install the electronics fasteners while the underside is accessible, then screw the carrier onto the bracket from its front. No washers are included in the modeled stack. The wall-contact plane is 13 mm behind the carrier underside, leaving at least 4 mm between the existing battery screw tips and the pad fronts.

Put one mating pair of [Command narrow 17207 strips](https://www.command.com/3M/en_US/p/d/b5005604166/) on each rear pad, with removal tabs downward. Remove the carrier first for full tab access. These are two additional pairs beyond the servo mount's two pairs. The [manufacturer's catalog outline](https://media.digikey.com/pdf/Data%20Sheets/3M%20PDFs/17207.pdf) is approximately 92 × 13 mm, comfortably inside each pad; check your delivered strips without trimming. Use a suitable smooth surface: 3M excludes textured walls. The strip's picture-hanging rating does not establish this assembly's tested load capacity.

The example converter is still 40 × 36 mm, not the measured selected module. A smaller board requires regeneration rather than simply tightening the jaws further.

## S2 Mini: use its two mounting holes

The official LOLIN S2 Mini has **two 2.0 mm mounting holes, 20.4 mm centre to centre**, at the antenna end opposite USB. The horizontal edge inset is 2.5 mm. The approximately 3.3 mm inset from the antenna edge is derived from the drawing geometry, not an explicitly dimensioned measurement. Confirm it on the actual board before printing the final mount.

The design uses two small standoffs and M1.6 through screws/nuts, leaving 7 mm under the PCB for underside components and direct-solder joints. M1.6 gives nominal clearance through a 2.0 mm PCB hole; do not force an M2 screw through it. Keep screw heads/nuts and support footprints clear of antenna copper and populated areas. Any extra support near the USB end must land on a clear area of the actual board.

Sources: [official dimension drawing](https://www.wemos.cc/en/latest/_static/files/dim_s2_mini_v1.0.0.pdf), [official board photograph](https://www.wemos.cc/en/latest/_static/boards/s2_mini_v1.0.0_1_16x16.jpg).

## Buck-boost module: insulated edge capture

**Thickness audit:** the current clips have a 2.0 mm opening around an assumed 1.6 mm PCB. Neither that thickness nor the 40 × 36 mm board outline is verified for the received converter. The seller provides no dimensioned board drawing. See the [booster fit audit](../hardware/cad/battery-retention-v6/booster-fit-audit.md); do not treat these existing clips as a confirmed fit. Changing the old thickness config alone does not resize the hard-coded geometry.

The selected B0GCW44FDL module has no mounting holes. The concept uses adjustable insulating jaws on a removable sled. Lower shelves support suitable bare PCB edges; upper lips capture those edges against lifting, and stops prevent sliding. The screws and nuts sit outside the PCB footprint.

Jaw positions, underside clearance and capture height depend on the **actual PCB thickness, component placement, solder joints and clear edge areas**. No clamp should press on the inductor, capacitors or soldered wires. If the delivered board has no suitable bare edges, this concept must change to a component-specific cage. The old 40 × 36 × 18 mm reserved space is not a board specification.

## Earlier battery option: v5 adjustable retainers

The printed v4 bars were loose and covered the power switch. The seller's dimension photo distinguishes a **19 mm case body** from **22.5 mm including the switch projection**. The earlier solid 22.5 mm reference missed this distinction. The actual nominal case top is therefore Z22 on the 3 mm carrier, leaving 4 mm below the old bars. The cradle also has 1.4 mm total clearance on both horizontal axes.

Use the [v5 replacement kit and assembly instructions](../hardware/cad/battery-retention-v5/README.md). Two fixed side rails reuse the four existing posts and **four M3 × 35 mm screws/nuts**. Two central adjusters use **two additional M3 × 10 mm screws and two M3 nuts**, already included in the selected M3 assortment, to press through printed load-spreading pads. Select small shims to remove horizontal play. Tighten only until the case stops moving; do not squeeze or bow it.

Install the holder with its switch facing outward. The photo-derived model places the switch near the lower-right corner and keeps the retaining contacts near the middle instead. The wire exits near the upper-right edge; the old bottom-center cradle notch does not align with this orientation. Follow the v5 routing clearance rather than pulling the wire through the wrong notch. Loosen the retainers and lift the case to reach its battery cover; leave enough wire slack for this.

Sources: [selected holder](https://www.amazon.com/dp/B09N1GDWQ9), [seller dimension photo](https://m.media-amazon.com/images/I/61-SB+loQyL._AC_SL1500_.jpg), [reproducible pixel estimates](../hardware/cad/battery-retention-v5/photo-measurements.json). Switch features are photo estimates with at least ±1 mm allowance, not measured dimensions of the delivered case. The v5 physical fit remains to be checked after printing.

## Before approving physical fit

Confirm the actual S2 hole position/diameter and underside clearance. Measure the converter's PCB length, width, thickness, height above/below the PCB, and identify bare clamp areas. Measure the closed battery holder including switch/seams and locate its lead exit. Then test the screw access, removal path and retention on small printed interfaces.

The current BOM is [here](../BOM.md). The previous [v2 fit-test tray](electronics-carrier-v2.md) remains available for reference; its mesh checks did not establish complete component retention.

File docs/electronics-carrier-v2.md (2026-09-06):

# Electronics carrier v2 — fit-test revision

**Retention is being redesigned:** use the [v3 mounting review](electronics-retention.md) for S2 screw mounts, converter edge capture and battery retaining bars. This v2 tray is an earlier fit-test layout, not the final component mount.

This revision is for the current **headerless ESP32-S2 Mini + DAIERTEK switched four-AA holder + Teyleten Robot B0GCW44FDL buck-boost module**. It is a separate carrier beside the approved one-servo actuator. The breadboard stays on the bench.

**Full-carrier physical fit is not approved.** The selected converter has no verified mechanical drawing, and the actual holder, solder joints and USB plug have not been measured. An exported STL can be a valid printable solid without fitting those components. Start with the supplied fit-test pieces and keep the full carrier as a draft until the checks below pass.

- [Current BOM CSV](../hardware/s2-current-bom.csv)
- [Independent component/source audit](s2-electronics-component-audit.md)
- [Current electrical wiring](s2-aa-poc.md)
- [Approved separate servo mechanism](servo-command-mount.md)

## Review files and STL exports

- [Full assembly in Blender](../hardware/cad/electronics-carrier-v2/generated/full-assembly-review.blend) — approved actuator geometry plus revised electronics carrier.
- [Full assembly image](../hardware/cad/electronics-carrier-v2/generated/full-assembly-review.png)
- [Electronics-only Blender model](../hardware/cad/electronics-carrier-v2/generated/electronics-carrier-v2.blend)
- [Draft full carrier STL](../hardware/cad/electronics-carrier-v2/generated/electronics_carrier_v2_DRAFT_FIT_TEST.stl) — **120 × 160 × 10 mm; physical fit pending**.
- [Battery outline fit ring](../hardware/cad/electronics-carrier-v2/generated/holder_fit_ring.stl) — **76.1 × 71.6 × 2 mm**; tests the case perimeter only.
- [S2 corner-support fit coupon](../hardware/cad/electronics-carrier-v2/generated/s2_corner_support_coupon.stl) — **35.4 × 44.3 × 10 mm**; tests the nominal corner supports and underside clearance, not full retention.
- [Independent exported-STL verification](../hardware/cad/electronics-carrier-v2/generated/independent-verification.json)
- [Generator verification](../hardware/cad/electronics-carrier-v2/generated/validation.json)

The revised tray has a 3 mm floor and a 7 mm nominal clearance beneath the S2. The USB connector faces outboard; the 12 × 20 × 10 mm plug volume is an allowance, not a measured cable. Minimum tie-slot width is 3.5 mm for nominal 2.5 mm ties. Battery slots are 4.5 mm wide and require narrow reusable ties, not wide hook-and-loop straps. The holder lifts out for its back switch and screw cover. The converter rests over a continuous floor and requires a removable insulating spacer selected after inspecting its underside; this is not a completed converter retention design.

## Problems found in the previous carrier

Independent reviewers found blocked converter strap slots, 2 mm slots narrower than the referenced 2.5 mm ties, converter rails that a smaller PCB could not span, a USB socket facing the battery with no verified plug clearance, and a battery-strap opening leaving only 0.4 mm to the tray edge. The old assembly also shows the superseded broad wall chassis instead of the approved narrow Command-strip actuator.

The previous mesh was closed and connected and fit the A1 bed. Those checks did not detect the assembly problems above. The new revision and its independent mesh review must address both geometry and assembly access.

## What must be checked on the actual parts

With batteries removed and USB disconnected:

1. **Converter:** measure PCB length and width, overall height including underside solder joints, and any projecting components. Record input/output wire exits. The exact selected ASIN matters; dimensions of a similar-looking module are not a substitute.
2. **Holder:** measure the loaded, closed case, then locate its back switch, cover screw, lid opening direction and lead exit. Its seller nominal outline is 68.7 × 64.2 × 22.5 mm. Retention must allow removal to operate/access the back and replace cells.
3. **S2:** check the actual board outline against the nominal 25.4 × 34.3 mm. Look under the board for components and solder joints that would touch a support. Plug the actual USB cable in and check room for the plug and cable bend. Do not compress components, solder pads or antenna with a strap.
4. **Harness:** inspect the soldered wire diameter and bend space, heat shrink and strain relief. Mechanical wire references are not pin assignments; follow the wiring document.
5. **Retention:** insert the actual straps/ties into the printed slots. Confirm a small converter rests securely on its insulating support and cannot slide into solder joints or wires. A large empty bay alone does not establish retention.

## Print and use scope

The fit-test pieces check only the interfaces they reproduce. An outline ring alone cannot validate a populated PCB's underside, its retention, or USB access. Inspect the supplied verification report for the exact scope of each coupon.

Use the Bambu A1 in millimetres and inspect the slicer preview before printing. Do not print the component reference blocks, USB cable envelope, labels or presentation surface. Keep the already-approved servo STL files separate from the draft electronics carrier.

The battery carrier needs its own support; its weight must not be hung from the servo attachment. No carrier wall-attachment method has been physically validated. Bench assembly and dry fit come before powered operation.

## Independent review results

Three agents reviewed component sources, mechanical design and exported mesh geometry. The final independent verifier reads the STL triangles directly: all three parts are single closed, consistently wound solids at Z=0 within the A1 envelope. All ten slots are open; measured slot apertures are 3.5 or 4.5 mm, with a minimum 3.25 mm outer-edge ligament. Samples confirm the continuous 3 mm converter floor, nominal battery clearance and 7 mm S2 underside clearance. No downward-facing surface exceeding 45 degrees occurs above the bed; a slicer inspection is still required.

The combined preview uses `servo-command.blend` at frame 1. A separate Blender comparison found its mount and paddle equivalent to the approved STL shapes, with at most 0.000004 mm numerical deviation after rigid placement normalization. The previously edited Blender files and approved servo STLs were not overwritten.

Regenerate with Blender's background mode and `hardware/cad/electronics-carrier-v2/generate.py`, then run `python3 hardware/cad/electronics-carrier-v2/verify_independent.py`. Generate the combined preview using `assemble_review.py`. Mesh checks do not remove the physical-fit blockers listed above.

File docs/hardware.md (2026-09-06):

# Hardware and fit

**Historical reference — earlier Pico design; not the current build instructions.** For the current ESP32-S2 Mini POC, start with [S2 wiring](s2-aa-poc.md), [S2 firmware](s2-firmware.md) and the [current BOM](../BOM.md).

## What the switches are called

The photo shows **decorator rocker switches**, also called **paddle switches** or **Decora-style switches**, in a **two-gang wallplate**. Decora is Leviton's brand name; the shape alone does not identify the manufacturer. The bedroom version is a one-gang decorator wallplate. “Gang” counts adjacent device positions; it does not identify whether the switch circuit is single-pole or three-way. [Leviton product terminology](https://leviton.com/content/dam/leviton/distribution-marketing/program-support/ED-G-00213%20MPG%20Growth%20Brochure.pdf).

Reference dimensions below are starting presets, not measurements of the photographed plate. Plate perimeter dimensions differ even where the device opening is compatible. [Leviton's wallplate size guide](https://leviton.com/content/dam/leviton/commercial-industrial/product_documents/solution_sheets/Wallplate%20Size%20Guide%20Q-1289.pdf).

| Plate | One gang, width × height | Two gang, width × height |
| --- | --- | --- |
| Standard | 69.85 × 114.3 mm | about 115.9 × 114.3 mm |
| Midway | about 79.4 × 123.8 mm | about 125.4 × 123.8 mm |
| Oversize | 88.9 × 133.4 mm | about 134.9 × 133.4 mm |

The guide adds about 46 mm width per additional gang. Curvature, thickness, screw heads, and manufacturers' tolerances still matter. The photo has perspective distortion and no scale; it cannot establish a snug fit.

Measure with the existing plate installed:

1. Overall width and height; maximum projection from the wall; corner radius and edge bevel.
2. Each moving paddle's width, height, center location, and top/bottom projection in both positions.
3. Gap between two paddle centers; the mounting cannot assume the paddle is centered perfectly in its opening.
4. Travel at the contact points and approximate force at those points (a small push-force gauge is useful).
5. Your actual MG90S body, ear spacing, shaft height, stock horn holes, and retaining screw.
6. The purchased battery holder and regulator board, including plugs and cable bend space.

Print the fit frame before the complete chassis. The generated models are an adjustable prototype. Do not infer a fit approval from an STL file existing.

## Mechanism

Use one servo for each paddle to control both office lights independently. Use the supplied servo horn and its original shaft screw; fasten the printed arm to the horn's holes. Do not print a guessed spline or substitute a screw that bottoms in the output shaft. A horn needs a positive torque connection; its center screw alone should not transmit all the torque through smooth plastic.

A servo shaft parallel to the wall lets a double-ended arm rock toward the upper or lower end of the switch. Soft contact pads take up small alignment differences. The arm briefly presses, returns to a position with both tips clear, then loses electrical power. Manual operation must remain possible at rest. Start with the servo unmounted and the arm removed, center it, then assemble and calibrate in small increments. Never run an assumed full 180° sweep against the switch.

For fixed shaft torque, a longer servo arm gives **less contact force**: `F = torque / radius`. It increases reach and displacement per degree. Pressing farther from the light switch's own pivot can reduce the force needed to click that switch. These are two different levers. As an ideal illustration, 1.8 kgf·cm is about 0.176 N·m; a 30 mm horn radius would produce about 5.9 N at stall. Real useful force must be lower, with margin; stall torque is not a continuous operating point.

The equal-and-opposite pressing force pulls the housing outward. At offset `d` from its support, adhesive also experiences a peeling moment `F × d`. A longer horn does not cancel that load. Use a broad stiff frame, supports close to both contact points, shallow projection from the wall, compliant tips, and the minimum travel that clicks the switch. Adhesive pull ratings cannot be treated as cyclic peel ratings. Repeated pressing, wall texture, paint adhesion, temperature, and battery weight all need a real test. Keep adhesive removal tabs accessible and never glue the moving paddle. A sleeve around a plate locates the device but does not, by itself, resist pulling off the wall.

All installation and testing in this project remains outside the intact wallplate: no wiring, mains access, longer wallplate screws, or modifications to the electrical switch. Stop testing if the frame lifts, the switch does not click freely, or the servo buzzes after pressing. A software duration limit is useful but is not independent current sensing or a mechanical overload clutch.

## Board and servo identification

Pico/Pico H lack wireless hardware. Pico W/Pico WH include Wi-Fi; headers do not change this. The existing non-wireless Pico can run the servo bench code over USB. For this project's Mac mini gateway and phone UI, the node needs a **Pico W/WH or Pico 2 W** with its matching MicroPython firmware and a 2.4 GHz Wi-Fi network. The user has a wireless board; verify the exact model before flashing. A Pico is a microcontroller, not a Linux Raspberry Pi. [Raspberry Pi board variants](https://www.raspberrypi.com/documentation/microcontrollers/pico-series.html).

TowerPro lists an MG90S body of 22.8 × 12.2 × 28.5 mm, 1.8 kgf·cm stall torque at 4.8 V, and 4.8 V operating voltage. Its own page contains mixed voltage references and warns about lookalike products. It does **not** provide a stall-current specification there. The “MG90S” name on an Amazon listing does not establish exact dimensions, shaft/horn geometry, safe pulse endpoints, or current consumption. Confirm the supplied servo's rated supply range before using the proposed regulated 5 V rail; do not interpret the page's 6.6 V torque entry as blanket permission to use that voltage. [Original TowerPro MG90S page](https://towerpro.com.tw/product/mg90s-3/).

Start with a supply path designed for roughly **2 A available to one moving servo plus logic**, and measure the actual loaded peaks. This is a design allowance, not a sourced MG90S current rating. Serialize commands on the double unit; two simultaneous stall/start currents require a larger verified power path. Larger servos and lookalikes may require more. [Power wiring and test sequence](power.md).

## Selected parts for revision 2

The first version used placeholder component envelopes and an unspecified servo load-switch carrier. The current headerless revision selects actual purchasable parts so the enclosure can be designed around their mounting and connection requirements:

| Function | Selected component |
| --- | --- |
| Removable batteries and contacts | Pololu 1153 four-AA holder with its supplied red/black leads |
| Cells | Four matched Panasonic eneloop AA NiMH cells; external NiMH charger |
| Regulated 5 V | Pololu 2574 / S18V20F5 |
| Master and servo switches | Two Pololu 2810 **LV slide-switch** modules; different control wiring for each |
| Direct Pico mounting | Headerless Pico W, four M2 × 6 nylon screws and soldered edge-pad wires; no PiCowBell |
| Passive components and soldered junctions | Adafruit 1608 quarter-size Perma-Proto |
| Battery disconnect | Mating Pololu 2180 + 2181 JST RCY prewired pigtails |
| Protection and wiring | Selected fuse/holder, diodes, capacitor, resistors, servo mating leads and power wire in the shopping list |

The root [BOM](../BOM.md), [BOM CSV](../hardware/bom.csv) and [shopping list](shopping-list.md) give manufacturer/order identifiers, source links and quantities. The [wiring guide](wiring.md) maps those parts to the existing GP15/16/17/26 firmware pins, including connector polarity and actual physical Pico pin numbers. The 2810 is an assembled high-side module; it replaces the earlier generic TPS22918 suggestion.

The [component-source register](component-sources.md) separates manufacturer dimensions, conservative fit allowances and unresolved measurements. A part number freezes the intended purchased part; it does not eliminate manufacturer tolerances, solder protrusion or variation in third-party MG90S servos. The revised CAD checks nominal component placement and clearance. The small fit coupons and a bench assembly still verify the actual printed and purchased parts.

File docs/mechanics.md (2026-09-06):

# Mechanical prototype: headerless Pico W revision

**Historical reference — earlier Pico design; not the current build instructions.** For the current ESP32-S2 Mini POC, start with [S2 wiring](s2-aa-poc.md), [S2 firmware](s2-firmware.md) and the [current BOM](../BOM.md).

The photo shows **Decora-style / decorator paddle rocker switches in a two-gang wallplate**. “Decora” is Leviton's trademark; “decorator rocker” is the generic search term. One gang is the matching single-switch arrangement. Gang count does not establish single-pole versus three-way wiring.

This revision uses manufacturer dimensions and the official Pico W reference geometry, with explicit assembly clearances. **It is not yet a verified fit to your particular servo, soldered harness, battery holder or installed wallplate.** Print the small fit coupons and record the remaining measurements before printing the complete assembly. All parts stay outside the existing plate; this design does not require opening the switch or attaching anything behind it.

## What the Blender scene contains

`hardware/cad/config.json` is the editable dimensional configuration. `generate.py` creates both assemblies, exports millimetre STLs, and saves `generated/auto-switch.blend` and `assembly.png`. Objects marked `PRINT` are printed parts. `VENDOR Pico W` objects are the eleven components tessellated from Raspberry Pi's original STEP model. `COMPONENT` objects show purchased parts; `KEEPOUT` wireframes show service allowances. Component objects include their dimensional basis as Blender custom properties. Coupons and lids are hidden in the assembly preview, but available in the Outliner.

The Pico W mesh includes its actual board outline, mounting holes, connector and major components. The current default has no headers or carrier. Four nylon M2×6 screws mount the headerless board directly. Pico 2 W shares the published board footprint, but **the Pico W mesh is not an exact model of Pico 2 W's components**. The selected headerless board and actual solder/wire protrusion still require confirmation. See [component provenance](component-sources.md) and the [vendor notice](../hardware/components/vendor/NOTICE.md); third-party geometry retains its original license.

The holder, four AA cells, regulator, master switch, servo power gate, fuse holder, battery connector, prototyping board and illustrative wiring appear as separate objects. Manufacturer envelopes are distinguished from illustrative internal details. The perfboard placement is a component-space example, not a completed pad-by-pad board layout. The full circuit and connection order are in [wiring.md](wiring.md).

## Construction and mounting

- Each plate surround has 0.7 mm clearance per side, a 9 mm skirt and two 20 × 78 mm external adhesive lands. These are locating features; no unmeasured snap hooks are hidden behind the plate.
- A **separate universal electronics pod** bolts to either surround using two docking straps. The pod has 170 × 158 × 40 mm nominal internal space, a 4 mm floor and a removable lid. Individual print parts fit the A1 bed; the assembled device is substantially larger than a single wallplate. The enclosure is intentionally spacious for soldered wiring and removable batteries.
- The sideways MG90S is retained through its mounting ears using two M2 × 10 mm screws, nuts and washers. The provisional slots accommodate a 26–29 mm ear-hole pitch; this is not proof that the user's servo matches. The ear thickness, hole dimensions, shaft position, cable exit and horn remain unverified. The mounting coupon checks these before a large print.
- A two-ended yoke screws to the supplied **double-arm servo horn**. The original centre screw secures that horn to the spline. A 4.4 mm access hole provides screwdriver access. The provisional horn holes are 2.2 mm diameter, 14 mm apart. Measure the horn and use short compatible screws; do not force a printed spline onto the servo. A single-arm horn needs a revised flange or a matching replacement horn.
- The contact posts receive two bought **3M SJ5302 round bumpers, nominal Ø7.9 × 2.2 mm**, per servo. These compliant contacts are not calibrated force limiters.
- The headerless Pico uses its four published mounting holes and Ø3.9 mm printed posts; M2×6 nylon screws enter pre-tapped M2×0.4 pilots. The PCB underside sits at Z=8 mm above a Z=4 mm floor, leaving 4 mm below the board. A 3 mm subset is reserved for solder and wires. The other boards use shelves and removable edge retainers because exact mounting-hole coordinates are not consistently available. The battery holder sits on raised feet, has corner locators and uses straps through channels entirely above the enclosure floor. Two short ties retain the fuse holder through paired eyes; four more ties secure the wire harness through raised eyes. No tie or fastener protrudes between the enclosure back and wall.

The pictured wall is textured. **The selected Command 17201 strips explicitly exclude textured walls; do not use them there, and do not treat a trial adhesion test as overriding that restriction.** The adhesive lands are usable only with a mounting product approved for the actual surface. A suitable external mechanical mount or separately supported prototype is still needed for this wall. The present CAD does not solve that installation constraint. Do not remove the electrical wallplate or add screws into the switch box to improvise an attachment.

## Dimensional evidence and remaining fit checks

| Component or feature | Basis in this revision | Still to confirm |
|---|---|---|
| Pico W PCB | Official STEP; nominal 51 × 21 × 1 mm; hole pitch 47 × 11.4 mm, Ø2.1 mm | Headerless W selection and actual solder protrusion |
| TowerPro MG90S reference | Drawing: case length 22.8, width 12.4, case height 28.4, shaft-tip height 32.5, ear span 32.1 mm | User's manufacturer; ear-hole pitch, thickness, shaft offset, spline and horn |
| Pololu 1153 holder | Bare envelope 63 × 58 × 16 mm in this orientation | Loaded height; 22 mm is a reserved allowance, not a sourced loaded measurement |
| Pololu 2574 regulator | Published 43 × 21 × 10 mm envelope; drawing approximately 43.2 × 21 mm | Soldered wire bends and underside protrusions |
| Two Pololu 2810 switches | 15.24 × 15.24 mm PCB; 2.54 mm published height | Slider travel, wire bends and tool access |
| Adafruit 1608 PermaProto | Published 43 × 50.8 mm | Assembled circuit routing and exact actual board |
| Littelfuse fuse holder | 47.5 ±1 mm long, Ø11 mm | Cap removal, trimmed lead routing and retention |
| RCY and USB plugs | Explicit service envelopes, not exact manufacturer shell meshes | Actual molded plugs and unplugging clearance |
| One-/two-gang wallplate | Reference 69.85/115.9 × 114.3 mm; 46 mm gang pitch | Actual outside width, height, taper, depth and rocker travel |

Published dimensions and links are cataloged in [component-sources.md](component-sources.md) and [shopping-list.md](shopping-list.md). TowerPro's abbreviated product dimensions conflict slightly with its drawing; this model follows the drawing and does not assume all “MG90S” products are interchangeable. “All metal” commonly describes gears rather than the outer case.

Measure the plate while installed. Print `1g_fit_ring.stl` or `2g_fit_ring.stl` first. The thin ring checks the outline, not skirt depth or rocker travel. Print `coupon_servo_ear_mount`, `coupon_battery_holder`, `coupon_pico_mount` and each relevant board cradle with its corresponding retainer. The battery coupon is a 22 mm open collar; separately measure loaded height and wire exit. The Pico coupon checks the actual four post positions, tapped screw fit and underside solder clearance; the USB opening is in the full pod. Update the configuration and regenerate if anything fails. **Do not scale the whole STL**, because that changes screw and component interfaces together.

## Travel, force and manual operation

For torque τ and pad radius r, tangential force is approximately **F = τ/r**. A longer servo arm increases travel and reduces available force; reaching the switch's ends independently reduces the force required compared with pressing near its pivot. TowerPro's 1.8 kgf·cm stall rating at 4.8 V corresponds to roughly 6.8 N at a 26 mm radius, before losses. Stall is a limit, not an operating target.

Blender's frames 1–100 illustrate a ±10° upper/lower press, returning to neutral. The pivot is 31 mm above the wall reference and pad radius 26 mm. The rigid posts must clear the rocker; only the compliant bumper should make contact. The configuration check evaluates the descending rigid corner at the configured sweep. This does not establish real switch travel, calibrated servo pulse angles or full collision-free motion. Adhesive thickness, switch tilt, horn indexing and servo variations all change the contact position. Start at neutral and advance in tiny increments off the wall; stop immediately after a switch clicks.

The short press and neutral return reduce sustained force, but the mounting still carries the reaction force and battery weight. No force sensor, spring-return clutch or physical torque limiter is included. Check manual access at neutral. If power fails during a press, disconnect the low-voltage supply and remove the externally attached assembly or horn rather than forcing the paddle against servo gears.

## Printing and assembly

The A1's 256 × 256 × 256 mm build volume accommodates each exported part. The separate pod and lid are nominally 174 × 162 mm in XY. With the pod mounted above the surround and the lid closed, **both complete layouts occupy approximately 174 × 300.7 × 47 mm** (width × height × depth), excluding adhesive thickness and plug insertion space. Refer to `generated/validation.json` for all current dimensions. Leave room for slicer supports or brim; bed-fit checks do not include those additions.

1. Print and test the fit coupons first. Record every required measurement in the configuration before committing to full parts.
2. Print the surround and pod flat back down. PETG with a 0.2 mm layer, four perimeters and 25–35% infill is a starting point. Inspect bridge and overhang supports in the slicer. No universal G-code is provided.
3. Print each yoke in its exported side orientation; inspect support placement around the offset flange. Print the lid, four retainers and **two copies of `docking_strap.stl`**. Pilot holes are intended for careful screw threading in plastic; test first and avoid overtightening.
4. Pre-tap the Pico mounting coupon and posts M2×0.4, then fit the headerless Pico with four M2 × 6 nylon screws; use sixteen M2.5 × 8 screws across four retainers. Four M3 × 8 screws attach the lid. Four M3 × 6 screws and four M3 nuts attach the two docking straps. Each servo requires two M2 × 10 screws with matching nuts/washers, plus the original horn centre screw and measured compatible horn screws.
5. Fit and insulate the circuit following the wiring guide. Cut the selected servo extension to retain its male mating plug with roughly 100 mm of lead after a dry fit; solder those leads directly to the power board. Do not coil a full 12-inch extension inside this layout. The original servo stays unplug-removable. Keep the USB and antenna service areas free of added metal and wiring.
6. Test with a supported assembly and suitable spare switch before any wall installation. Check horn clearance, neutral return, fuse access, battery removal, connector polarity and cable strain relief. Resolve the textured-wall mounting method before attaching the loaded device.

## Regeneration and limits of validation

```sh
/Applications/Blender.app/Contents/MacOS/Blender --background --factory-startup --python-exit-code 1 --python hardware/cad/generate.py
python3 hardware/cad/verify_stl.py
/Applications/Blender.app/Contents/MacOS/Blender --background hardware/cad/generated/auto-switch.blend --python-exit-code 1 --python hardware/cad/audit_fit.py
python3 tools/verify_bom.py
python3 tools/render_bom.py
open -a /Applications/Blender.app hardware/cad/generated/auto-switch.blend
```

Blender is sufficient to reproduce the model with its bundled Python; FreeCAD is a free alternative for later constraint-driven CAD work. The vendor STEP conversion is already included and need not run to regenerate this scene.

The generator requires one connected manifold volume per printable. Independent STL checks verify manifold edges, positive volume, bed origin and A1 bounds against the generated manifest. The fit report checks nominal component-body containment and separation, the four retainer envelopes against adjacent component bodies and each other, and retainer clearance from the lid-pillar envelopes. It also records installed assembly bounds and measurements still required. These checks do not certify manufacturing tolerance, complete wiring routes, all component/shelf contacts, dynamic collisions, print strength, servo torque, adhesive durability, RF performance or electrical temperature. The render is a design preview, not a built and tested device.

## BOM linked to exported meshes

The [root BOM](../BOM.md) lists installed single/two-gang quantities, exact selections, print quantities and unresolved interfaces. [BOM fit report](bom-fit-report.md) is the readable check summary; the underlying `generated/bom-fit-report.json` records the hashes of each STL actually audited. `audit_fit.py` independently reads STL triangles, transforms them back into the saved assembly, computes nominal component/STL intersection volumes, and probes the Pico mounting holes, solder space and USB port. Thus its evidence concerns the actual exported files, not just a matching list of nominal dimensions.

The remaining measurement gates and unresolved textured-wall mount are intentional limitations. A green geometry check does not make this a print-and-install kit. The board circuit is not pad-by-pad routed, all wire bends and complete fasteners are not simulated, and the servo/horn geometry still needs identification.

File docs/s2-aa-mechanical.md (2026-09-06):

# ESP32-S2 Mini + switched AA prototype mechanics

This revision separates a **single-gang wall actuator** from an **independently mounted electronics carrier**. It uses the new DAIERTEK four-AA holder and a LOLIN S2 Mini reference outline. The battery weight is carried by its own mounting surface rather than added to the servo's wallplate attachment. Keep the breadboard on the bench for the first circuit test; its model, outline and rail arrangement have not been identified. The carrier is the next step after breadboard testing, with female jumpers connecting the S2 Mini off the breadboard.

**Prototype status: print small fit coupons first. These STLs are not a claim of exact fit to the user's unmeasured hardware.** There is no verified size drawing for the purchased converter, no measured wallplate, and no confirmation that the user's S2 Mini and MG90S match the reference manufacturers. An adjustable bay is deliberate; an invented exact converter would hide the missing information.

## Files and operation

- [Blender assembly](../hardware/cad/s2-aa-poc/generated/s2-aa-prototype.blend)
- [Rendered assembly](../hardware/cad/s2-aa-poc/generated/assembly-preview.png)
- [Parameters](../hardware/cad/s2-aa-poc/config.json)
- [Reproducible generator](../hardware/cad/s2-aa-poc/generate.py)
- [Mesh and sweep report](../hardware/cad/s2-aa-poc/generated/validation.json)
- [Independent STL report](../hardware/cad/s2-aa-poc/generated/stl-verification.json)

Open the `.blend` and press Space over the 3D view to preview neutral, +10°, neutral, −10°, neutral over frames 1–85. This animation illustrates movement; it is not a validated firmware calibration. One Blender unit represents one millimetre. STL exports are individually centered in XY and placed on Z=0 in millimetres.

```sh
/Applications/Blender.app/Contents/MacOS/Blender -b --factory-startup --python hardware/cad/s2-aa-poc/generate.py
python3 hardware/cad/s2-aa-poc/verify.py
```

## Component dimensions and evidence

| Item | Used geometry | Confidence and remaining measurements |
|---|---|---|
| DAIERTEK switched 4-AA case, Amazon B09N1GDWQ9 | 68.7 × 64.2 × 22.5 mm outer case | Seller nominal dimensions from the project holder research. Physical case, switch projection, lid release and lead exit remain unmeasured. The model's small switch position is illustrative. |
| LOLIN S2 Mini V1.0.0 | 25.4 × 34.3 mm PCB outline | Official WEMOS drawing and product specification. Board thickness is provisionally 1.6 mm; underside soldered headers and components are cosmetic fit references. Actual clone, header rows and connectors require inspection. |
| MG90S | 22.8 mm case length, 12.4 mm width, 28.4 mm housing height, 32.5 mm base-to-shaft tip, 32.1 mm ear span, 18.5 mm base-to-ear underside | TowerPro dimension table. This is not proof of the user's servo dimensions. Ear thickness 2 mm, hole pitch 27.5 mm, shaft offset 5.2 mm and supplied horn geometry are assumptions requiring measurement. |
| Teyleten Robot Amazon B0GCW44FDL | **No exact component geometry**. Pink wireframe reserves 40 × 36 × 18 mm | Product picture shows XL63070 silk, while seller title specifies TPS63070. Mechanical drawing was unavailable. Reserved volume is a design allowance, not measured size. Revise it if the delivered PCB/inductor/wires exceed it. |
| Existing wallplate | Provisional single-gang 69.85 × 114.3 × 6 mm | Default inherited from earlier project, not measured from the photograph. This does not fit arbitrary jumbo plates or the office double-gang plate. |
| Existing rocker | 31.5 × 65 mm, front plane Z=10 mm | Visual proxy only. Measure travel, active surface height and contact force. |
| Soft contact pads | 3M SJ5302 nominal 7.9 mm diameter × 2.2 mm height | Existing project pad choice; requires two physical pads or a re-dimensioned suitable substitute. Not included in printable STL. |

Sources: [DAIERTEK Amazon listing](https://www.amazon.com/dp/B09N1GDWQ9), [previous holder research](aa-holder-research.md), [WEMOS S2 Mini](https://www.wemos.cc/en/latest/s2/s2_mini.html), [official dimension PDF](https://www.wemos.cc/en/latest/_static/files/dim_s2_mini_v1.0.0.pdf), [TowerPro MG90S](https://towerpro.com.tw/product/mg90s-3/), [existing servo evidence](component-sources.md), [converter listing](https://www.amazon.com/dp/B0GCW44FDL).

## How the mechanism works

The servo sits beside the rocker with its output shaft **parallel to the wall**. A dual-ended orange paddle rocks toward the upper or lower end of the switch, then returns to neutral. Contact pads are 26 mm from the axis. At 10° rotation, the end travel due to radius alone is about 4.5 mm; the rearward pad offset also affects its path. Neutral pad-to-proxy-rocker gap is approximately 3.7 mm. Actual rocker travel determines calibration.

The longer paddle reaches the ends of the rocker; it does **not** increase available pressing force for the same servo torque. Force is approximately torque divided by contact radius. Starting gently near neutral, limiting dwell and returning to neutral reduce the chance of peeling off the fixture. Adhesive load capacity, wall paint, servo stall behavior and frame strength have not been experimentally validated.

The supplied plastic horn remains on the servo spline with its original center screw. Two small fasteners attach the printed flange to that horn through adjustable slots at approximately ±7 mm radius. The center access hole allows the original center screw to be removed. Do not substitute an unverified screw thread into the servo. Verify horn thickness, fastener diameter and available arm holes before printing the paddle. It intentionally has no printed spline.

**The photographed wall is textured. The previously selected Command 17201 strips explicitly exclude textured walls: do not use them on this wall, and an adhesion trial does not override that restriction.** The printed wings are only generic mounting surfaces, not approval for adhesive installation. Use a separately supported bench fixture for this prototype until an external mechanical support or mounting product approved for the actual surface has been designed. Do not remove the wallplate or add screws into the electrical box to improvise support.

The two servo ear towers have clearance slots around 28.5 mm pitch, allowing the reference 27.5 mm hole pattern. Their screws need M2-size through hardware and nuts selected after the actual ears are checked. The wing backs provide broad surfaces for a future compatible mounting method. If removable adhesive is used on a manufacturer-approved smooth surface, arrange its pull tabs so they remain reachable. The assembly lifts away as a whole to restore full manual access; the narrow neutral paddle also leaves the rocker sides exposed.

## Electronics carrier

The black AA case rests on raised saddles with 0.7 mm nominal clearance per side. Two reusable straps feed through the adjacent slots to retain it; remove the straps for battery replacement. Keep straps clear of the lid catch, switch and wire exit after inspecting the delivered holder.

The S2 Mini rests at four PCB corners, with 20 mm between the carrier floor and the board underside for headers and female jumper plugs. The center is open and the antenna end is kept away from the battery. Corner geometry and strap position must be dry-fitted to the actual board; avoid pressing straps onto components or the antenna. The open top provides USB, boot and reset access. The detailed USB plug body and cable bend are not exact models.

The converter bay has adjustable tie slots and raised edge supports, **not source-matched mounting holes**. Fit a separate insulating support to the actual board, then retain it with ties/straps without loading components or solder joints. Verify clearance under the PCB and airflow around the inductor before powering it. Until dimensions are known, use the converter on the bench and do not treat the bay as ready to fasten the actual board.

Both carriers need independent support; attachment to the photographed textured wall remains unresolved. No fastener enters the electrical wall box and no mains wiring is modified. Carrier-to-carrier wiring is a route illustration, not an electrical schematic; use the S2-specific wiring diagram as the electrical authority.

## Prints and additional mechanical items

| STL | Purpose |
|---|---|
| `01_plate_fit_ring.stl` | Cheap outer plate fit check before the large chassis |
| `02_wall_chassis.stl` | Frame, adhesive wings and servo ear towers |
| `03_factory_horn_paddle.stl` | Moving paddle; uses stock horn and separate soft pads |
| `04_electronics_carrier.stl` | Open battery/S2/adjustable-converter tray |
| `05_battery_fit_ring.stl` | Check seller case outline plus 0.7 mm per-side allowance |
| `06_s2_outline_coupon.stl` | Check reference PCB outline plus 0.7 mm allowance |

Additional mechanical items: an external support appropriate to the mounting surface (Command 17201 strips are excluded on the photographed textured wall); two soft contact pads; reusable battery straps; board/converter retention ties with insulation where needed; two servo ear fasteners/nuts; two horn fasteners; original servo horn and original center screw. Exact lengths and threads are not established from the available photos. Existing electrical BOM components alone do not complete the mechanical assembly.

All parts fit within the Bambu A1's 256 mm build envelope. PETG is a reasonable prototype material; begin with the 2 mm coupons. Use adequate perimeters around the ear towers and inspect layer adhesion. Paddle export is rotated to place its broad side near the bed; slicer support review is still necessary for the flange and contact feet. Mesh validity is not proof of structural strength or support-free printing.

## Verification performed and required

The generator rejects non-manifold print meshes, disconnected printable pieces and nonpositive volume. It samples the paddle at every integer degree from −10° through +10° and checks the actual meshes for intersections with the printed chassis. It also checks the servo-body reference against the chassis. An independent Python reader checks every exported STL for exactly two incident triangles per edge, positive volume, bed placement and A1 size. These checks do not validate wall adhesion, servo force, real component tolerances or all possible wire collisions.

Before printing the full assembly, measure the plate width/height/projection, rocker face/travel, actual MG90S body/ears/shaft/horn, actual S2 outline and loaded header height, delivered battery case including its lid and switch, and converter PCB width/length/tallest component plus wire exits. Update `config.json` and regenerate. The office's two-gang design will need a separate measured frame; this revision intentionally prototypes one switch.

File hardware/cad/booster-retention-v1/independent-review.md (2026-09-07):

# Independent booster fit-test review

**PASS for the assumed 16 × 30 × 1.2 mm reference board only.** This verifies the new printed mechanism against its saved nominal model. It does not establish the delivered board's thickness, underside clearance, soldered-wire clearance or actual contact patches.

[review_mechanics_independent.py](review_mechanics_independent.py) loads the saved assembly and reads the five binary STL files. Results are recorded in [generated/independent-mechanical-review.json](generated/independent-mechanical-review.json); the audit saves no CAD changes.

## Contact and screw stack

Both end-center support shelves measure **Z6.5** at the contact patches. Both finger undersides measure **Z7.7**, giving the modeled PCB exactly **1.2 mm** between support and finger. The shelves are 2.8 mm wide and 1.6 mm deep, supporting the nominal 0.6 mm finger overlap and its inward adjustment range. The two upper contacts sit between the modeled corner pads, rather than on components or terminal pads.

Both screw hard seats measure **Z7.3**. Each included shim is **0.4 mm thick**, bringing the finger seat to Z7.7. Those shims are required for the default 1.2 mm PCB model. Without them the fingers sit lower; do not simply omit them with this board assumption.

Low end stops finish at **Z7.22**, below even the unshimmed seat. This corrects the study's taller stops, which would have prevented lower finger adjustment. The audit confirms that the fingers can reach their hard seats without colliding with those stops. Low side-guide inner faces measure **X±8.2**, giving 0.2 mm per-side allowance around the nominal 16 mm PCB. Anti-rotation key inner faces measure **X±4.3**, giving 0.2 mm per side around each 8.2 mm finger foot.

Two **M3×16 screws** pass through the fingers, shims, adapter and carrier, into ordinary M3 nuts. The under-head plane is Z9.7, so the screw tips end at Z−6.3. With the nuts ending at Z−2.4, each screw projects 3.9 mm beyond the nut. The existing wall-bracket pad-front plane is Z−10, leaving 3.7 mm of nominal clearance. Hole probes verify the local Y±23 positions: **46 mm pitch**, mapping to carrier X22/Y22 and X22/Y68.

## Retention and clearance

The mechanism restrains width with low side guides, length with two short-end stops, and lift with the two removable fingers. Direct supports beneath the finger patches prevent the design from relying on PCB bending. The keyed feet resist finger rotation, while the screws clamp them onto printed seats rather than providing unlimited downward adjustment.

**100 exact Boolean intersection checks returned zero volume.** These cover printed parts against the approximate solder-pad/component references, intended PCB clearances, finger-to-adapter clearance, and the mounting-shaft paths. Intended planar contact is offset by 0.001 mm during the checks to avoid coplanar numerical artifacts. The component references are approximate, so these results are not proof of clearance around the real module or its solder fillets.

Outward sliding can remove the finger overlap; the nominal position must be checked during assembly. The fixed tray also has finite width/length clearance, so the slotted fingers do not make this a universal adjustable holder. Wires need separate strain relief; the current adapter does not include a dedicated wire clamp.

## Print geometry

All five exported parts have their flat faces at **Z0** and **zero suspended downward-facing area**. The adapter's mounting ears were widened to 12 mm so the anti-rotation guides have support beneath them; the narrower study ears would have left 0.7 mm ledges. Approximate exported sizes are:

| Part | Quantity | Dimensions |
|---|---:|---|
| Adapter | 1 | 20 × 58 × 6.2 mm |
| End finger | 2 | 8.2 × 13.6 × 2 mm |
| Height shim | 2 | 7.8 × 11 × 0.4 mm |

The generator checks each part is connected and manifold; the parent agent independently audits the final combined STL. Use 0.2 mm layers to preserve the two-layer shims. No physical fit, clamp strength, creep, vibration or thermal test has been performed. Dry-fit without power and revise the contact stack if it forces or bends the board.

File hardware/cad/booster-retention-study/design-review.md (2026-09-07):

# Independent booster retention design review

This is a design study, not a fit-approved model. It considers the actual XL63070-marked module shown in `IMG_3222.JPG` and `IMG_3223.JPG`, together with the existing V7 carrier geometry. A roughly **16 × 30 mm board** is a provisional photo estimate supplied by the parallel photo study; neither board thickness nor underside component/solder clearance is established.

## Recommended starting concept

Use a small replacement adapter on the existing carrier, with **two narrow removable fingers over the centers of the board's short ends**. Keep the terminal pads and most of the board exposed. Low side guides locate the long edges without overlapping their component faces. Relieved supports beneath verified bare areas carry the board; the fingers prevent it lifting out.

The top photo shows a blue center strip between the two terminal pad groups at each short end. Those two central patches appear more usable than the crowded long edges. The side photo also shows that the existing retaining walls are much taller than this actual low-profile module. Continuous long-edge retaining lips or broad end crossbars would risk touching parts or obstructing the four soldering areas.

A **2.8 mm wide finger with approximately 0.6 mm overlap** onto each short end is a reasonable provisional shape to preview. It is not yet an approved contact footprint: the available center-strip width, solder spread after wiring and real edge position must be checked. Each narrow tip should widen into its mounting body; avoid a long, uniformly thin tongue.

## How the board is restrained

| Motion | Restraint | Important detail |
|---|---|---|
| Sideways across board width | Two low side guides | Touch the cut substrate edge; do not assume a continuous bare top strip. |
| Along board length | Short-end shoulders or keyed finger bodies | The upper finger alone does not stop sliding unless it also includes an end stop. |
| Toward the carrier | Relieved supports under verified bare underside patches | Keep solder joints and through-pad wire ends clear of the support. |
| Away from the carrier | The two short-end center fingers | Small upper-face overlap, away from terminal pads and components. |
| In-plane rotation | Separated side guides and both end stops | One screw per finger needs a key/guide so the finger itself cannot pivot. |
| Pull from wiring | Separate strain relief attached to the adapter/carrier | The solder pads and narrow fingers should not carry cable tugging loads. |

The holder should geometrically capture the board. It should not depend only on squeezing it hard enough that friction prevents movement.

## Adjustment and screw load path

Make each finger a guided removable part, with an elongated mounting hole for modest length adjustment. A molded key or parallel guide walls constrain rotation; a lone screw in a round hole is insufficient for a predictable finger position. A guide must still allow the finger to retract far enough to insert and remove the board after the wires are soldered.

**The mounting screw should tighten the finger against a printed seat, not continue driving the finger into the circuit board.** Give the finger a defined underside height above the adapter's support surface. For initial fit tuning, small 0.2 mm increments of seat shims or a short set of finger-height variants are simpler to inspect than an unrestricted pressure screw:

- A shim under the finger's mounting foot raises its capture height.
- A shim under a verified board support raises the board toward a fixed finger; it must not sit under a solder joint or component.
- The final stack should remove perceptible lift without bending the board. Do not use mounting-screw torque to compensate for an incorrect height.

A lightly compliant finger could take up a small residual gap, but its travel must be limited by a hard stop. Its stiffness and long-term relaxation depend on geometry, material and temperature, so it is a secondary option requiring a printed trial. A free screw pressing directly on the board or a component is not the preferred design.

## Comparison of alternatives

| Option | Advantages | Weaknesses for this board |
|---|---|---|
| **Keyed short-end center fingers and low side guides** | Uses the apparently clear spaces between pad pairs; removable; exposes components; allows a small adapter. | Center contact patches and underside support areas still need verification; wire routing must pass beside the fingers. |
| Continuous grooved side rails | Captures vertical and sideways motion with few parts. | Right long edge is crowded; a groove assumes known PCB thickness and bare face margins. Sliding installation is awkward after wiring. |
| Four corner clips | Familiar positive capture. | All four corners contain terminal pads; clips could obstruct soldering or bear on solder/wires. Poor starting choice here. |
| Adhesive-backed cradle | Simple and tolerant of outline variation. | Underside topography and heating are unknown; replacement/inspection is less convenient; adhesive creep and removal forces complicate retention. |
| Strap across the module | Adjustable and easy to prototype. | A strap route can load the inductor or other components. It requires verified support/contact zones and should not become the default workaround. |
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

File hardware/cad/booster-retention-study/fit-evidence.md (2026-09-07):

# Received XL63070 board: mounting evidence and options

Reviewed user photos `IMG_3222.JPG` (top) and `IMG_3223.JPG` (side), and the current v4 converter cassette reused by the later carrier designs. **No production STL generated.**

## What is now established

The received board is labeled **XL63070**, with four terminal pad groups at the corners, a central inductor, and EN/PS/ADJ/output-selection pads along one long edge. It visibly does not match the old 40 × 36 mm placeholder. Its plated terminal holes are electrical connections, not identified mounting holes.

The photographed printed floor corresponds to the v4 26 × 36 mm center floor. Comparing the board to that floor gives a rough **30 × 16 mm PCB estimate**. This is an image-based estimate, not an exact measurement: camera perspective, board height above the reference, feature selection, and actual print scale all affect it. The side photo confirms a thin substrate with taller parts above it; it does not establish substrate thickness.
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

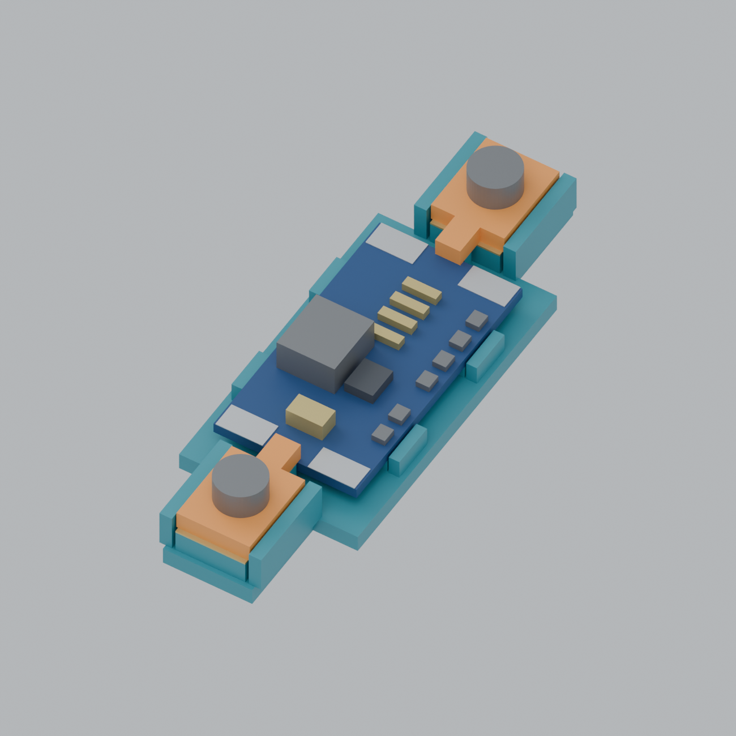
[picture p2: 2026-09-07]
hardware/cad/booster-retention-study/generated/recommended-end-fingers-PROVISIONAL.png

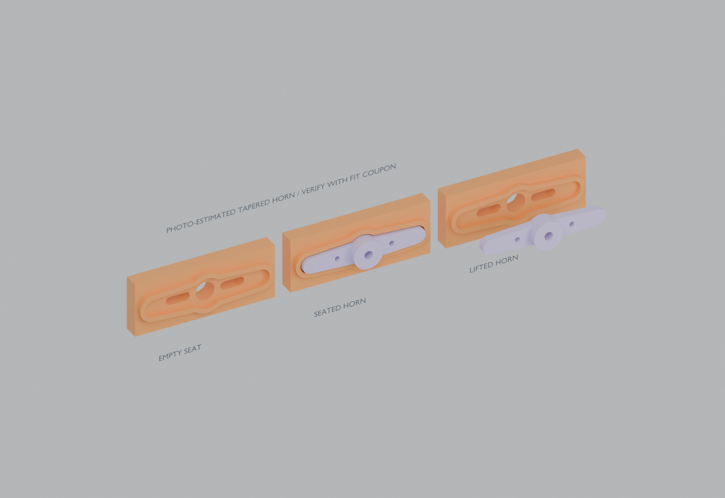
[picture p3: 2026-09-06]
hardware/cad/horn-pocket/generated/horn-seat-closeup.png

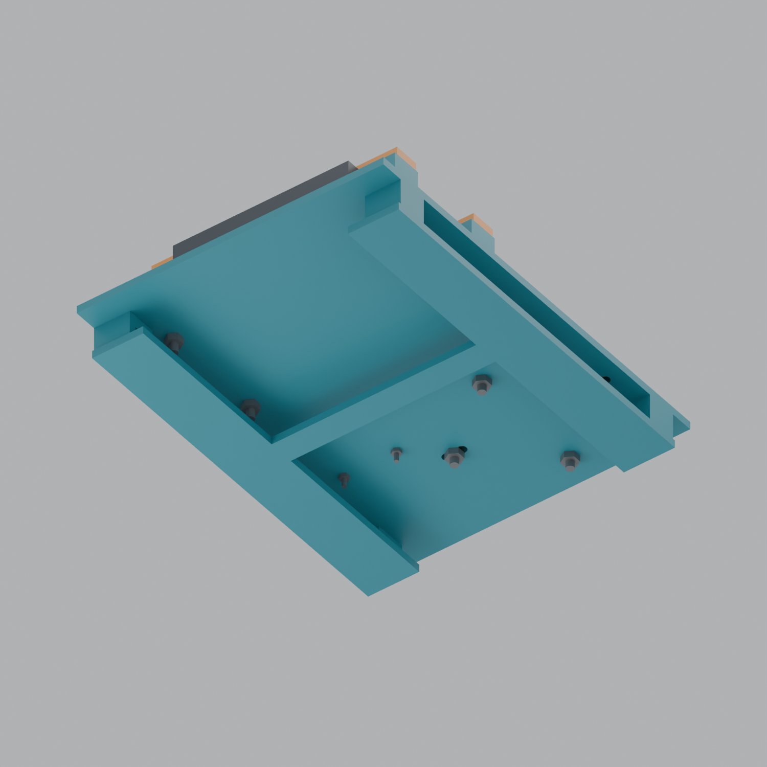
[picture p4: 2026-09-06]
hardware/cad/electronics-retention-v4/generated/rear-pads-v4.png

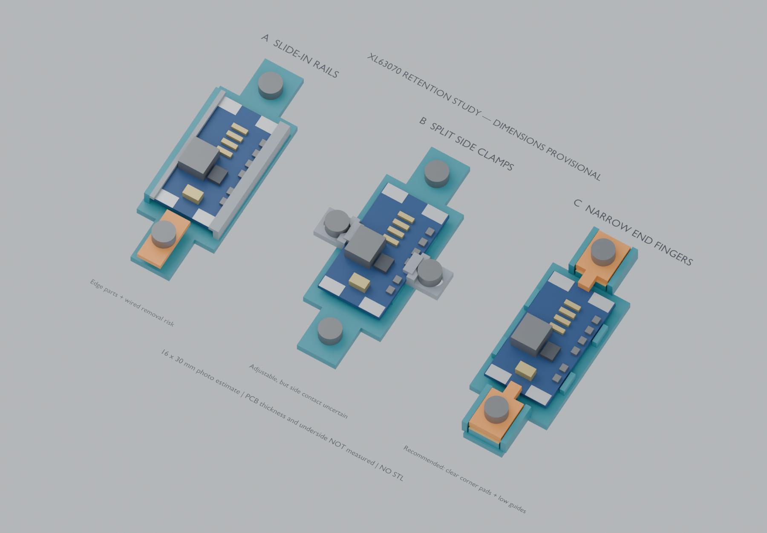
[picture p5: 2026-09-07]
hardware/cad/booster-retention-study/generated/booster-retention-options-PROVISIONAL.png

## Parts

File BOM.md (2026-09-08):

# Parts for the current POC

One bedroom paddle switch, one servo, and an **ESP32-S2 Mini hosting the On/Off website**. The board is currently tested on USB; the portable battery circuit is planned.

| Part | Quantity | Selection / status |
|---|---:|---|
| Headerless ESP32-S2 Mini | 1 | User-owned, running MicroPython; direct-solder connections |
| MG90S 180° micro servo | 1 | User-owned; reuse its stock horn and centre screw |
| [DAIERTEK switched four-AA holder](https://www.amazon.com/dp/B09N1GDWQ9) | 1 | Received; seller drawing shows 64.2 × 68.7 × 19 mm case, 22.5 mm including switch; approximately 150 mm leads |
| Amazon Basics 1.5 V AA alkaline batteries | 4 | Ordered; go inside the holder |
| [Teyleten Robot 5 V buck-boost module](https://www.amazon.com/dp/B0GCW44FDL) | 1 | Received: PCB labeled XL63070; exact dimensions still needed |
| Breadboard and jumper wires | 1 set | User-owned; bench assembly only |
| Dedicated SPST ESP32 power-isolation switch | 1 | User-owned rocker switch candidate; placed only in booster 5 V → ESP32 VBUS branch. Verify its DC rating and actual terminal labels; see [USB wiring](docs/usb-wifi-setup.md) |
| USB-C data cable | 1 | User-owned; programming and USB-only tests |
| Solder, heat shrink and wiring tools | As needed | User-owned |

The received converter PCB is labeled XL63070 (confirmed in the user’s photos); the selected listing calls it TPS63070. Match the received module to the [wiring guide](docs/s2-aa-poc.md) and verify its output with the multimeter. The older LM2596 buck-only board is not the selected AA converter.

## Printed mechanism and retention

- **Servo mount and paddle:** [approved STL exports and fit instructions](docs/servo-command-mount.md).
- **Narrow Command strips:** [17207 listing](https://www.amazon.com/dp/B09XJDK6RS), four mating pairs (eight individual strips) total: two pairs for the actuator and two for the separate electronics wall bracket. Check the actual smooth mounting surface and strip thickness.
- **Horn/servo fasteners and two soft contact pads:** select to fit the actual servo and printed mechanism; reuse the original spline screw.
- **Electronics holder:** [mounting guide](docs/electronics-retention.md). Print the [v7 carrier and centered flat battery bar](hardware/cad/battery-retention-v7/README.md), and reuse the separate wall bracket. The battery bar uses two M3 × 30 screws/nuts. Optional v5 shims address sideways play. The old booster clips failed physical fit; the [option C replacement fit-test](hardware/cad/booster-retention-v1/README.md) uses two M3 × 16 screws and two M3 nuts. [All revised pieces share one STL](hardware/cad/revision-print-v8/README.md), with booster dimensions still provisional. Two M1.6 screws/nuts attach the S2 through its factory holes; its existing attachment geometry is retained.

The electronics tray is separate from the actuator. Its wall bracket is modeled, but adhesive retention and component fits remain physically unverified. The converter still uses a placeholder envelope and must be measured before its fit can be approved.

[Detailed quantities, wire checklist and fit status (CSV)](hardware/s2-current-bom.csv) · [Current wiring](docs/s2-aa-poc.md)

The [earlier Pico/gated BOM](docs/history/pico-bom.md) is retained only as a historical reference.

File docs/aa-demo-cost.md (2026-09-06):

# One-servo AA demo — price calculation

**Historical reference — earlier Pico design; not the current build instructions.** For the current ESP32-S2 Mini POC, start with [S2 wiring](s2-aa-poc.md), [S2 firmware](s2-firmware.md) and the [current BOM](../BOM.md).

Researched **2026-09-05**, **USD**, for the current one-servo bench BOM. **Budget about $160 before tax and shipping**, with a working range of **$147.79–$181.79**. This is a purchase budget including retail packs and spares, not the value of only the pieces installed in one switch.

Reuse the user's Pico, one MG90S, and soldering kit. Assume the existing programming cable is reusable. The main total includes new solid/stranded wire sets and heat-shrink because the specifications of the user's existing wire and kit contents are unknown. A multimeter is needed for assembly checks; its ownership is unknown, so its purchase is shown separately.

Observed prices came from supplier pages or indexed Amazon offer text; none is a live checkout quote. Four Amazon prices remain unverified and use explicit allowances. Tax, shipping, cart tariffs, seller changes, coupons and subscriptions are excluded. **Do not interpret an allowance as a confirmed Amazon offer or maximum price.** Nothing was purchased.

| Material | Buy quantity | Purchase cost | Price basis / source |
| --- | --- | ---: | --- |
| [Existing Pico W / Pico 2 W](https://www.raspberrypi.com/documentation/microcontrollers/pico-series.html) | Reuse | $0.00 | Owned; no new purchase |
| [Existing MG90S + horn/screw](https://towerpro.com.tw/product/mg90s-3/) | Reuse one | $0.00 | Owned; no new purchase |
| [Four eneloop AA cells + charger](https://www.amazon.com/dp/B00JHKSMJU) | 1 kit | $29.00–$37.00 | Allowance; Amazon price unavailable. Exact-kit retailer references below. |
| [ELEGOO 830-point breadboards](https://www.amazon.com/dp/B01EV6LJ7G) | 1 three-pack | $8.99 | Observed Amazon indexed one-time price; excludes Subscribe & Save |
| [WAGO 221-415](https://www.amazon.com/dp/B06XH47DC2) | 1 ten-pack; use 3 | $8.00–$15.00 | Allowance; Amazon price unavailable. Exact-part retailer references below. |
| [TUOFENG 22 AWG solid-wire kit](https://www.amazon.com/dp/B07TX6BX47) | 1 six-color set | $16.00–$25.00 | Allowance; Amazon price unavailable. Same-ASIN retailer reference below. |
| [BNTECHGO 22 AWG stranded-wire kit](https://www.amazon.com/dp/B01M0O1NXM) | 1 ten-color set | $13.28 | Observed Amazon indexed one-time price; excludes Subscribe & Save |
| [Pololu 1153 AA holder](https://www.pololu.com/product/1153) | 1 | $2.99 | Observed Pololu quantity-1 price |
| [Pololu 2574 5 V regulator](https://www.pololu.com/product/2574) | 1 | $29.95 | Observed Pololu quantity-1 price; no coupon assumed |
| [Pololu 2810 master switch](https://www.pololu.com/product/2810) | 1 | $4.49 | Observed Pololu quantity-1 price |
| [Pololu 2180 RCY pigtail](https://www.pololu.com/product/2180) | 1 | $2.95 | Observed Pololu quantity-1 price |
| [Pololu 2181 RCY pigtail](https://www.pololu.com/product/2181) | 1 | $2.95 | Observed Pololu quantity-1 price |
| [Pololu 2169 servo extension](https://www.pololu.com/product/2169) | 1 | $5.25 | Observed Pololu quantity-1 price |
| [Littelfuse 01500274Z fuse holder](https://www.digikey.com/en/products/detail/littelfuse-inc/01500274Z/29453) | 1 | $4.00 | Observed DigiKey quantity-1 price |
| [SCHURTER 0001.2507 fuses](https://www.digikey.com/en/products/detail/schurter-inc/0001-2507/639706) | 3; install 1 | $3.15 | 3 × $1.05 at DigiKey |
| [CHANZON 1N5819 diodes](https://www.amazon.com/dp/B079KG1TN2) | 1 100-pack; use 1 | $5.00–$10.00 | Planning allowance only; no usable price obtained for this exact Amazon listing |
| [Panasonic EEU-FR1A471 capacitors](https://www.digikey.com/en/products/detail/panasonic-electronic-components/EEU-FR1A471/9921021) | 2; install 1 | $1.42 | 2 × $0.71 at DigiKey |
| [Yageo 1 kΩ resistors](https://www.digikey.com/en/products/detail/yageo/MFR-25FBF52-1K/13011) | 10; install 1 | $0.42 | 10 × $0.042 at DigiKey quantity-10 tier |
| [Optional separate jumper kit](https://www.adafruit.com/product/1957) | Do not buy | $0.00 | Make jumpers using the solid wire already counted |
| [Adafruit 344 heat-shrink pack](https://www.adafruit.com/product/344) | 1 pack | $4.95 | Observed manufacturer search listing; skip if already owned |
| [USB data cable](https://www.adafruit.com/product/3879) | Reuse | $0.00 | Assumed existing MicroPython programming cable; replacement excluded |
| [Multimeter](https://www.adafruit.com/product/850) | Reuse, otherwise add below | $0.00 | Ownership unknown; conditional $24.95 purchase below |
| Soldering kit and hand tools | Reuse | $0.00 | Existing kit; any missing tools excluded |
| Cable ties + nonconductive bench base | Small supply allowance | $5.00–$10.00 | Planning allowance; reuse stock to reduce this |

## Calculation

- Pololu parts: $2.99 + $29.95 + $4.49 + $2.95 + $2.95 + $5.25 = **$48.58**.
- DigiKey fuse holder, three fuses, two capacitors and ten resistors: $4.00 + $3.15 + $1.42 + $0.42 = **$8.99**.
- Observed Amazon breadboard and stranded-wire packs: $8.99 + $13.28 = **$22.27**.
- Heat-shrink manufacturer listing: **$4.95**.
- **Observed-price subtotal: $84.79**. This excludes the unpriced items; it is not a complete build price.
- Allowances: battery kit $29–37 + WAGO pack $8–15 + solid wire $16–25 + diode pack $5–10 + ties/base $5–10 = **$63–97**.
- **Total: $84.79 + $63–97 = $147.79–$181.79** before checkout extras.

| Purchase scenario | Before tax, shipping and tariffs |
| --- | ---: |
| Buy listed materials; reuse Pico, servo, soldering tools, USB cable and meter | $147.79–$181.79 |
| Same, but also buy the [Adafruit 850 multimeter](https://www.adafruit.com/product/850) at its observed $24.95 price | $172.74–$206.74 |
| Existing solid/stranded wire meets the BOM specifications and heat-shrink is already available; reuse meter | $113.56–$138.56 |
| Reuse suitable wire and heat-shrink, but buy that meter | $138.51–$163.51 |

If a USB cable, wire stripper, cutters or another tool is missing, add its actual purchase cost. An installed 3D-printed chassis, adhesive, mounting fasteners, filament, and print electricity are **not included**: this is the present bench build, and the revised enclosure has not been finalized. No invented print mass is used.

## Evidence and unverified Amazon prices

- [Amazon ELEGOO B01EV6LJ7G](https://www.amazon.com/dp/B01EV6LJ7G): indexed offer text explicitly lists **One-Time Price $8.99**; $8.54 is a subscription offer and was not used.
- [Amazon BNTECHGO B01M0O1NXM](https://www.amazon.com/dp/B01M0O1NXM): indexed offer text explicitly lists **One-Time Price $13.28**; $12.62 is a subscription offer and was not used.
- Battery kit allowance: [Walmart exact K-KJ17MCA4BA kit](https://www.walmart.com/ip/39111784) shows **$28.99**, sold/shipped by marketplace seller MY BATTERY SUPPLIER. [Best Buy exact kit](https://www.bestbuy.com/product/panasonic-eneloop-charger-and-4-aa-batteries-kit-white/J7SVP2JWPZ/sku/12562373) shows **$36.94 but sold out**. These are reference prices only; neither establishes the Amazon price or seller authenticity.
- WAGO allowance: [Ace exact 221-415 ten-pack](https://www.acehardware.com/departments/lighting-and-electrical/boxes-fittings-and-conduit/cable-connectors/3014063) shows **$7.99**. [DigiKey 221-415](https://www.digikey.com/en/products/detail/wago-corporation/221-415/13549457) shows **$1.17 each**, or **$9.91 for ten**. Buying only three from DigiKey would be **$3.51** before shipping. These are purchasing alternatives, not a change to the circuit.
- Solid wire allowance: [TekShack listing identifying B07TX6BX47](https://tekshack.com/products/22-awg-wire-solid-core-hookup-wires-6-different-colored-breadboard-wires-30ft) shows **$24.99**. The **$16 lower allowance is a budgeting assumption**, not a verified Amazon price.
- Diode pack: exact Amazon price unavailable; **$5–10 is solely a budgeting assumption**, not a sourced offer. A 100-pack is much more than this project needs; a small pack of the specified diode is sufficient, subject to the BOM's manufacturer/lead-size checks.
- [Adafruit 344 price-bearing manufacturer listing](https://www.adafruit.com/product/344?cPath=8) shows **$4.95**; [Adafruit 850](https://www.adafruit.com/product/850) shows **$24.95** in its indexed manufacturer listing.
- Pololu prices use quantity one. DigiKey uses the actual order quantities above, including the ten-resistor discount. Potential Pololu coupon savings were not applied; shipping and DigiKey cart tariff charges are not established.

## What drives the cost

The **$29.95 regulator** and the battery/charger kit are the largest individual entries. New wire sets and retail multipacks account for much of the first-build spending. The signal resistor costs **4.2 cents per piece at the selected quantity**, and a capacitor costs **71 cents**; these are not the expensive parts of this design.

The part numbers and wiring remain unchanged. Confirm the four missing Amazon prices before treating the total as an order-ready quote.

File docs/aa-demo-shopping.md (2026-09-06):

# AA demo: shopping list and bench hardware

**Historical reference — earlier Pico design; not the current build instructions.** For the current ESP32-S2 Mini POC, start with [S2 wiring](s2-aa-poc.md), [S2 firmware](s2-firmware.md) and the [current BOM](../BOM.md).

Checked **2026-09-05**. This list implements the [four-AA demo plan](aa-demo-plan.md): four matched NiMH cells, a fixed 5 V regulator, one physical master switch, a continuously powered servo, and no servo power gate or battery ADC circuit. The current build uses **one servo only**.

**Use the existing headered Pico and one MG90S servo.** This is a bench BOM. The old enclosure/STL fit report does not certify these new junction blocks, breadboard, connector routing, or assembly. Do not buy the old enclosure fasteners for this bench build.

**[Itemized price calculation](aa-demo-cost.md): about $160 before tax and shipping**, with a $147.79–181.79 planning range including new wire sets and retail packs. Missing Amazon prices are labeled allowances. Reuse and multimeter scenarios are included.

Source inspection records: [aa-demo-source-checks.md](aa-demo-source-checks.md).

Machine-readable quantities and purchasing notes: [aa-demo-bom.csv](../hardware/aa-demo-bom.csv). Quantities are installed parts, not packages: one battery kit already includes four cells and the charger. Nothing has been purchased.

## Amazon-first shopping

The direct Amazon pages below were opened and their product titles/variants checked. That establishes listing identity, not seller authenticity, live checkout stock, price, or a tested delivered sample. Amazon may change the selected variant. **No Amazon prices are quoted because a reliable current checkout price was not established.**

| Item | Installed: one servo | What to order | Why this selection |
| --- | --- | --- | --- |
| [Panasonic eneloop kit — B00JHKSMJU](https://www.amazon.com/dp/B00JHKSMJU) | 4 cells; 1 shared charger | **One** K-KJ17MCA4BA kit | Four AA NiMH cells and individual-cell charger. [Panasonic kit specification](https://www.panasonic.com/ca/consumer/batteries/rechargeable/eneloop/kkj17mca4ba.html). Remove cells from holder to charge. |
| [ELEGOO 830-point breadboards — B01EV6LJ7G](https://www.amazon.com/dp/B01EV6LJ7G) | 1 board | One three-pack; two spares | Manufacturer links to this ASIN. The terminal area has 630 holes, corresponding to 63 rows of ten, plus unused side rails. [Manufacturer](https://us.elegoo.com/products/elegoo-3pcs-breadboard-830-point-solderless-prototype-pcb-board-kit). |
| [WAGO 221-415 connectors — B06XH47DC2](https://www.amazon.com/dp/B06XH47DC2) | 3 blocks | One ten-pack; use three | One 5 V junction and two linked ground junctions. Buy genuine 221-415, not a visually similar unbranded block. [Manufacturer](https://www.wago.com/us/wire-splicing-connectors/compact-splicing-connector/p/221-415). |
| [TUOFENG 22 AWG solid copper wire — B07TX6BX47](https://www.amazon.com/dp/B07TX6BX47) | 1 m total allowance | One six-color set, or reuse equivalent | Solid wire makes breadboard jumpers and the leads connecting breadboard to WAGO blocks. Listing says solid tinned copper, six colors × 30 ft. |
| [BNTECHGO 22 AWG stranded copper wire — B01M0O1NXM](https://www.amazon.com/dp/B01M0O1NXM) | 2 m total allowance | One set, or reuse equivalent | Flexible power harness; ten colors × 10 ft. Use red for positive, black for ground. [Manufacturer](https://bntechgo.com/bntechgo-22-gauge-silicone-wire-kit-ultra-flexible-10-colors-each-10-ft-high-temp-200-c-600v-22-awg-silicone-wire-60-strands-of-tinned-copper-wi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). |
| [CHANZON 1N5819 diode — B079KG1TN2](https://www.amazon.com/dp/B079KG1TN2) | 1 diode | Listing is 100 pieces; a smaller traceable pack is sufficient | Amazon alternative advertised as DO-41, 1 A, 40 V Schottky. Its exact manufacturer/lead geometry has not been independently verified; see reference-grade fallback below. |

Have at least **1 m total solid wire and 2 m total stranded wire** available for this bench build, including at least 1 m red and 1 m black stranded wire. These generous cutting allowances replace the earlier 0.5 m/1 m estimates; supplied holder/RCY/servo-extension leads are additional. The selected sets exceed these quantities. Keep power leads short after a physical dry fit; the large drawing is not a cable-length template.

The solid-wire set can make all breadboard jumpers; a separate Dupont kit is not required. Optional [Adafruit 1957 male/male jumpers](https://www.adafruit.com/product/1957) are convenient for board-only logic connections. Keep the selected 22 AWG solid leads for WAGO connections. ELEGOO's separate 120-piece Dupont kit specifies copper-clad aluminum, so it is not the selected soldered harness material. [ELEGOO jumper material](https://us.elegoo.com/products/elegoo-multicolored-dupont-wire-kit).

## Specialty parts to order by exact model

I could not verify reliable exact Amazon listings for these selections. These manufacturer/distributor links avoid substituting an adjustable or step-up-only regulator, wrong connector family, or unknown fuse.

| Part | Installed quantity | Order | Connection or important detail |
| --- | --- | --- | --- |
| [Pololu 1153 four-AA holder](https://www.pololu.com/product/1153) | 1 | 1 | Includes 6-inch 24 AWG leads. Bare holder is 58 × 63 × 16 mm; loaded height and access still need measurement. |
| [Pololu 2574 S18V20F5](https://www.pololu.com/product/2574) | 1 | 1 | Fixed regulated 5 V, step-up and step-down. Direct-solder to VIN, GND, VOUT; ENABLE unused. Current capability varies with battery voltage and heat. |
| [Pololu 2810 LV master switch](https://www.pololu.com/product/2810) | 1 | **1, not 2** | Purchased slider-operated board. Use VIN, VOUT, GND; leave ON/control pads unused. No GPIO wire. |
| [Pololu 2180 female RCY pigtail](https://www.pololu.com/product/2180) + [2181 male RCY pigtail](https://www.pololu.com/product/2181) | 1 pair | One of each | Keyed battery disconnect, 100 mm leads. Recessed contacts on fused battery side. Verify actual continuity/polarity before connecting. |
| [Pololu 2169 servo extension](https://www.pololu.com/product/2169) | 1 | 1 | 300 mm, 22 AWG. Cut the extension, preserving the male-contact end that mates with the servo socket. Original servo cable stays intact. |
| [Littelfuse 01500274Z fuse holder](https://www.digikey.com/en/products/detail/littelfuse-inc/01500274Z/29453) | 1 | 1 | Enclosed inline holder with leads, fits 5 × 20 mm. Wire it close to battery positive. |
| [SCHURTER 0001.2507 fuse](https://www.digikey.com/en/products/detail/schurter-inc/0001-2507/639706) | 1 | 3: one fitted, two spares | 2 A time-lag, 5 × 20 mm, specified DC rating. [Manufacturer SPT table](https://www.schurter.com/en/datasheet/SPT_5x20). Still requires coordination against measured pack-current pulses and wiring. |
| [Panasonic EEU-FR1A471 capacitor](https://www.digikey.com/en/products/detail/panasonic-electronic-components/EEU-FR1A471/9921021) | 1 | 2: one fitted, one spare | C1, 470 µF, 10 V, polarized radial. Nominal Ø8 × 11.5 mm body, 3.5 mm lead pitch. [Manufacturer](https://industrial.panasonic.com/ww/products/pt/aluminum-cap-lead/models/EEUFR1A471). |
| [Yageo MFR-25FBF52-1K resistor](https://www.digikey.com/en/products/detail/yageo/MFR-25FBF52-1K/13011) | 1 | 10 shared spares | 1 kΩ, 1%, ¼ W axial, one per signal. [Manufacturer MFR series](https://www.yageogroup.com/content/Resource%20Library/Datasheet/YAGEO-MFR_DATASHEET.pdf). |

For a diode with a traceable manufacturer specification, select **Vishay 1N5819-E3/73** from an authorized distributor; [DigiKey exact-part search](https://www.digikey.com/en/products?keywords=1N5819-E3%2F73) is a search link, not a verified stock listing. Its [Vishay datasheet](https://www.vishay.com/docs/88525/1n5817.pdf) specifies a 1 A, 40 V DO-41 part and identifies the band as cathode. This datasheet does **not** certify the CHANZON alternative. The Vishay lead diameter can be 0.71–0.86 mm: if it does not insert gently into the breadboard, solder short 22 AWG solid-wire adapters and insulate the joints rather than forcing it.

## How the three junction blocks are used

Label the blocks **P5V**, **GND_A**, and **GND_B**. Every hole in one 221-415 is electrically common; these are not five separate circuits. Number the holes left-to-right as drawn. One wire per hole, no doubled-up conductors.

| Port | P5V: regulated positive | GND_A | GND_B |
| --- | --- | --- | --- |
| 1 | Regulator VOUT | Battery negative via RCY | Link from GND_A.4 |
| 2 | C1 positive | Master GND | Pico GND feed |
| 3 | D1 anode feed | Regulator GND | Servo 0 ground |
| 4 | Servo 0 positive | Link to GND_B.1 | Empty |
| 5 | Empty | C1 negative | Empty |

The selected WAGO accepts 24–12 AWG copper conductors; the manufacturer specifies an 11 mm strip length and an approximately 29.8 × 18.3 × 8.15 mm body. Leave space above its levers. Do not add solder to the ends clamped in the connector; factory tinned copper strands are different from a solder-coated bundle. Confirm full insertion and tug gently. [WAGO product](https://www.wago.com/us/wire-splicing-connectors/compact-splicing-connector/p/221-415), [WAGO CAD/specification record](https://wago-embedded.customer-domain.wago.com/3d-cad-models/221-485-splicing-connector-with-levers-for-all-conductor-types-max-4-mm-5-conductor-transparent-housing-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).

Solder an individually insulated 22 AWG pigtail to each capacitor lead, then connect to its assigned WAGO port. For the cut servo extension, power and ground go directly to the blocks; join its signal conductor to a short solid-wire end for the breadboard. Route the **motor current outside the breadboard**. The holder, fuse, master and regulator remain separate on a nonconductive base with strain relief.

## Tools and consumables

Reuse the soldering kit, suitable wire, and USB cable first. Fill these gaps if needed:

- A digital multimeter with DC volts, resistance, continuity and diode mode; [Adafruit 850](https://www.adafruit.com/product/850) is a concrete reference. Do not connect a meter in current mode directly across batteries.
- Thin-wall heat-shrink in small and medium sizes for individual solder joints; [Adafruit 344 assortment](https://www.adafruit.com/product/344) is a concrete reference. Slip it onto the wire before soldering.
- A **data-capable** USB-C to Micro-B cable for the Mac and Pico; [Adafruit 3879](https://www.adafruit.com/product/3879) is a reference. A charge-only cable cannot upload firmware.
- Wire stripper/cutter covering 24, 22, 20 and 16 AWG, electronics solder/flux, a suitable heat source for shrink, small cable ties, and a nonconductive bench base. The fuse holder and RCY leads differ from the new 22 AWG hookup wire.

For these generic consumables only: [Amazon heat-shrink search](https://www.amazon.com/s?k=heat+shrink+tubing+2%3A1+1mm+2mm+3mm+assortment), [USB data-cable search](https://www.amazon.com/s?k=USB+C+to+Micro+B+data+cable), and [multimeter search](https://www.amazon.com/s?k=digital+multimeter+DC+voltage+continuity+diode). **These are unverified search results, not selected or checked product listings.** An older Wirefy ASIN tested during research redirected to a different ¼-inch roll, so it was intentionally not recommended as a small-wire assortment.

## What is and is not verified

The BOM matches the selected electrical topology and accounts for connectors, power junctions, wires and tools. Exact mechanical fitting, soldering, breadboard contacts, loaded servo current, transient supply behavior and runtime have not been tested on the user's hardware. The new WAGO assembly has not been modeled into the old STLs. Battery operation is a supervised demo without automatic low-pack cutoff: charge cells externally and switch off before depletion. The ungated [AA-demo configuration](../firmware/config.aa-demo.example.json) now exists: it selects `hardware_profile: "aa-demo"`, `power_enable_pin: null`, and disables the absent battery ADC. Follow the [firmware guide](firmware.md) to install it and calibrate the initially disabled channel. This profile has not yet been verified on the physical device.

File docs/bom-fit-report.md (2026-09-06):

# BOM-to-STL fit evidence

**Historical reference — earlier Pico design; not the current build instructions.** For the current ESP32-S2 Mini POC, start with [S2 wiring](s2-aa-poc.md), [S2 firmware](s2-firmware.md) and the [current BOM](../BOM.md).

This is a **nominal digital fit audit**, not a report from a physically assembled unit. The current headerless Pico W build retains explicit measurement gates. See the [BOM](../BOM.md) and [machine-readable evidence](../hardware/cad/generated/bom-fit-report.json).

`audit_fit.py` reads the exported STL triangles, reconstructs their assembly placement, and checks the modeled purchased parts against those meshes using exact Boolean intersection volumes. It also ray-probes actual mounting holes and access channels. Coplanar seating contact and intersections below 0.05 mm³ are not treated as interference. Actual component tolerances, unseen wire bends and full dynamic motion remain outside that test.

## Automated results

| Check | Result | Evidence |
|---|---|---|
| 1-gang nominal component meshes versus exported STLs | PASS | 65 component meshes; 83 candidate intersections; 0 reported clashes. Exact Boolean volume intersections after bounding-box filtering; >0.05 mm³ reported. Coplanar seating contact allowed. Geometry is nominal; unidentified servo and cosmetic internal details remain provisional. |
| 2-gang nominal component meshes versus exported STLs | PASS | 76 component meshes; 95 candidate intersections; 0 reported clashes. Exact Boolean volume intersections after bounding-box filtering; >0.05 mm³ reported. Coplanar seating contact allowed. Geometry is nominal; unidentified servo and cosmetic internal details remain provisional. |
| Pico four M2 pilot holes and support rims in pod STL | PASS | 47×11.4mm source pitch; nominal 1.6 mm pilot must be tapped M2×0.4. Probes verify center cavity and support at 1 mm radius. |
| USB insertion rays through exported pod wall | PASS | Nine rays sample a 14×12 mm provisional plug corridor from socket mouth to exterior. Actual cable molded shell and neck length still require measurement. |
| STL collision detector controls | PASS | Known 4 mm³ probe inside floor must intersect; same probe in free air must not. |
| Headerless underside solder reserve probes | PASS | Nine vertical rays in 3 mm design reserve; excludes mounting rims. Actual solder/wire routing must be checked. |
| Loaded-holder reserved body versus actual pod STL | PASS | 63×58×22mm allowance, not measured loaded holder. Nominal feet meet its base; locators remain outside. |
| Fuse and harness tie channel probes | PASS | Twenty-four rays sample the paired fuse eyes and four wire-tie eyes. Chosen 2.5 mm ties use nominal 3.5×2.4 mm openings; latch heads and actual routes remain a physical check. |
| Capacitor maximum seated height allowance | PASS | 9×9×13mm reserve above PCB, including the 13 mm maximum seated height rather than only 11.5 mm nominal can height. |
| Selected Pico screw depth | PASS | M2×6 screw begins at PCB top 9 mm; tip at 3 mm leaves 3 mm between tip and wall-side back. Pilot bottom is 2.5 mm, leaving 0.5 mm screw-tip allowance; pre-tap without piercing the closed back. |
| Every BOM STL reference exists | PASS | Reads hardware/bom.csv directly; coupons are reference artifacts and not installed duplicates. |
| 1-gang installed print quantity map | PASS | One surround, one yoke per servo, pod, lid, four retainers, and two docking straps. |
| 2-gang installed print quantity map | PASS | One surround, one yoke per servo, pod, lid, four retainers, and two docking straps. |

All 21 exported STL files also pass independent manifold-edge, positive-volume, print-bed origin and A1 256 mm volume checks. The Blender exporter separately requires a single connected solid per printable. Bed checks exclude added slicer brims/supports. Saved report hashes bind the audit to the exact BOM, STL files and generator inputs; `python3 tools/verify_bom.py` rejects stale evidence.

## Per-part mapping and remaining work

A mapped STL means the part has a relevant modeled interface or reserved space; it does not imply every connector or wire has manufacturer CAD. Empty mappings identify external tools/consumables.

| Part | Associated STLs | Status and remaining check |
|---|---|---|
| Raspberry Pi Pico W (headerless) | [electronics_pod.stl](../hardware/cad/generated/electronics_pod.stl), [coupon_pico_mount.stl](../hardware/cad/generated/coupon_pico_mount.stl) | **nominal geometry; physical fit pending**. Official Pico W STEP includes the actual board, USB socket and major components. Direct solder five wires for one gang or six for two gangs. No carrier or headers. |
| Pololu 1153 | [electronics_pod.stl](../hardware/cad/generated/electronics_pod.stl), [coupon_battery_holder.stl](../hardware/cad/generated/coupon_battery_holder.stl) | **nominal geometry; physical fit pending**. Published bare-holder dimensions; loaded height and lead exits require measurement. Includes 6-inch 24 AWG leads. The loaded reserve is not a measurement. |
| Pololu 2574 S18V20F5 | [electronics_pod.stl](../hardware/cad/generated/electronics_pod.stl), [retainer_regulator.stl](../hardware/cad/generated/retainer_regulator.stl), [coupon_regulator_cradle.stl](../hardware/cad/generated/coupon_regulator_cradle.stl) | **nominal geometry; physical fit pending**. Envelope excludes optional terminal blocks. Direct solder harness keeps height down; preserve airflow. ENABLE unused. |
| Pololu 2810 Mini MOSFET Slide Switch LV | [electronics_pod.stl](../hardware/cad/generated/electronics_pod.stl), [retainer_master.stl](../hardware/cad/generated/retainer_master.stl), [retainer_servo_gate.stl](../hardware/cad/generated/retainer_servo_gate.stl), [coupon_master_cradle.stl](../hardware/cad/generated/coupon_master_cradle.stl), [coupon_servo_gate_cradle.stl](../hardware/cad/generated/coupon_servo_gate_cradle.stl) | **nominal geometry; physical fit pending**. No mounting holes; electrical through holes are not screw holes. One master, one GP15 servo gate. Physical gate slider OFF; master ON pin unused. Cable bend space additional. |
| Adafruit 1608 quarter Perma-Proto | [electronics_pod.stl](../hardware/cad/generated/electronics_pod.stl), [retainer_proto.stl](../hardware/cad/generated/retainer_proto.stl), [coupon_proto_cradle.stl](../hardware/cad/generated/coupon_proto_cradle.stl) | **nominal geometry; physical fit pending**. Exact 1608 board selected. Manufacturer was out of stock when researched; Mouser lists this part but live stock is unverified. Direct-wire the motor power; PCB bus current rating is not established. |
| Littelfuse 01500274Z | [electronics_pod.stl](../hardware/cad/generated/electronics_pod.stl) | **nominal geometry; physical fit pending**. Length tolerance ±1 mm. The cylindrical holder includes a 330 mm loop of 16 AWG wire to cut and trim. Two short ties positively retain it. A 70 mm service envelope is provisional. |
| SCHURTER 0001.2507 SPT 5x20 2A time-lag | [electronics_pod.stl](../hardware/cad/generated/electronics_pod.stl) | **standard 5×20 holder interface; verify actual assembly**. Ceramic, explicit DC rating; buy two spares. Fuse time-current coordination still needs measured input pulse and wiring validation. |
| Pololu 2180 JST RCY female pigtail | [electronics_pod.stl](../hardware/cad/generated/electronics_pod.stl) | **allowance only; measure and route actual item**. 100 mm, 20 AWG prewired lead. The 25×10×10 mm allowance covers the mated 2180/2181 shells; actual dimensions and cable bends need checking. Recessed contacts belong on the fused battery side. |
| Pololu 2181 JST RCY male pigtail | [electronics_pod.stl](../hardware/cad/generated/electronics_pod.stl) | **allowance only; measure and route actual item**. Matches 2180. JST RCY is rated 3 A with 22 AWG wiring; thicker wire does not increase the connector rating. |
| Pololu 2169 12-inch twisted servo extension | [electronics_pod.stl](../hardware/cad/generated/electronics_pod.stl) | **allowance only; measure and route actual item**. Purchased length 300 mm, 22 AWG. Cut to retain the male end with roughly 100 mm lead, trimmed after dry fit; solder to the component board. The original servo remains detachable. Unused female half is a spare. |
| Panasonic EEUFR1A471 | [electronics_pod.stl](../hardware/cad/generated/electronics_pod.stl), [retainer_proto.stl](../hardware/cad/generated/retainer_proto.stl) | **component body space only; board wiring not pad-routed**. 470 µF, 10 V polarized radial capacitor. C1 sits on unswitched regulated 5 V. Nominal can is Ø8×11.5 mm; reserve 13 mm maximum seated height above the PCB. Observe polarity. |
| KEMET C315C104K5R5TA | [electronics_pod.stl](../hardware/cad/generated/electronics_pod.stl), [retainer_proto.stl](../hardware/cad/generated/retainer_proto.stl) | **component body space only; board wiring not pad-routed**. 100 nF, 50 V X7R radial. Buy three: one installed for ADC filtering and two spares for bench bypassing if needed. |
| Vishay 1N5819-E3/73 | [electronics_pod.stl](../hardware/cad/generated/electronics_pod.stl), [retainer_proto.stl](../hardware/cad/generated/retainer_proto.stl) | **component body space only; board wiring not pad-routed**. 1 A, 40 V Schottky DO-41. D1: anode to 5 V, striped cathode to VSYS. D2: anode to GND, striped cathode to SERVO_5V; it clamps negative excursions, not positive overvoltage. |
| Yageo MFR-25FBF52-100K | [electronics_pod.stl](../hardware/cad/generated/electronics_pod.stl), [retainer_proto.stl](../hardware/cad/generated/retainer_proto.stl) | **component body space only; board wiring not pad-routed**. 1%, ¼ W axial. Battery-divider top and GP15 pulldown. Nominal body 6.3×Ø2.4 mm with ±0.5 mm length and ±0.2 mm diameter tolerance; leads are additional. |
| Yageo MFR-25FBF52-47K | [electronics_pod.stl](../hardware/cad/generated/electronics_pod.stl), [retainer_proto.stl](../hardware/cad/generated/retainer_proto.stl) | **component body space only; board wiring not pad-routed**. 1%, ¼ W axial; battery-divider bottom resistor. |
| Yageo MFR-25FBF52-1K | [electronics_pod.stl](../hardware/cad/generated/electronics_pod.stl), [retainer_proto.stl](../hardware/cad/generated/retainer_proto.stl) | **component body space only; board wiring not pad-routed**. 1%, ¼ W axial; one PWM signal resistor per servo and one switched-rail bleeder. |
| Adafruit 3111 22AWG stranded six-color spool set | [electronics_pod.stl](../hardware/cad/generated/electronics_pod.stl) | **allowance only; measure and route actual item**. Buy one shared spool set if existing wire is unsuitable. Budget about 1 metre total hookup wire per device, then trim after dry fit. Quantity is an allowance, not a spool consumed per device. |
| Adafruit 344 heat-shrink assortment | [electronics_pod.stl](../hardware/cad/generated/electronics_pod.stl) | **allowance only; measure and route actual item**. Shared consumable; insulate every soldered wire splice and exposed discrete lead. One shared pack across units; cut consumption unknown. |
| Adafruit 3879 USB-C to Micro-B 0.3m | [electronics_pod.stl](../hardware/cad/generated/electronics_pod.stl) | **allowance only; measure and route actual item**. Shared commissioning data cable, removed for normal battery operation. No panel adapter. The actual molded plug must fit the reserved service corridor. |
| Panduit PLT1M-C | [electronics_pod.stl](../hardware/cad/generated/electronics_pod.stl) | **allowance only; measure and route actual item**. Four wire strain-relief ties and two fuse-retention ties; paired printed fuse eyes and four harness eyes are included. Actual routing and latch clearance still need checking. Buy one shared pack, trim tails. |
| Existing MG90S 180-degree servo; TowerPro drawing reference | [1g_chassis.stl](../hardware/cad/generated/1g_chassis.stl), [2g_chassis.stl](../hardware/cad/generated/2g_chassis.stl), [coupon_servo_ear_mount.stl](../hardware/cad/generated/coupon_servo_ear_mount.stl) | **provisional; user brand and mounting dimensions unknown**. Use existing servos if measurements match; MG90S name alone is insufficient to guarantee fit. |
| Original matching double-arm servo horn | [1g_servo1_yoke.stl](../hardware/cad/generated/1g_servo1_yoke.stl), [2g_servo1_yoke.stl](../hardware/cad/generated/2g_servo1_yoke.stl), [2g_servo2_yoke.stl](../hardware/cad/generated/2g_servo2_yoke.stl) | **provisional; actual horn required**. Reuse the manufacturer-matched spline interface. Printed flange provisionally has 14 mm fastening pitch and Ø2.2 mm holes; measure the actual double-arm horn before printing. |
| Original servo horn centre screw | [1g_servo1_yoke.stl](../hardware/cad/generated/1g_servo1_yoke.stl), [2g_servo1_yoke.stl](../hardware/cad/generated/2g_servo1_yoke.stl), [2g_servo2_yoke.stl](../hardware/cad/generated/2g_servo2_yoke.stl) | **unverified thread; reuse original only**. Do not substitute guessed M2 screw into servo output shaft. |
| Horn-to-yoke screws: specification pending horn measurement | [1g_servo1_yoke.stl](../hardware/cad/generated/1g_servo1_yoke.stl), [2g_servo1_yoke.stl](../hardware/cad/generated/2g_servo1_yoke.stl), [2g_servo2_yoke.stl](../hardware/cad/generated/2g_servo2_yoke.stl) | **BLOCKED: exact fastener not selected**. Diameter, thread and length depend on actual horn; this is a disclosed missing purchase specification, not an approved part. |
| Panasonic eneloop AA NiMH (four matched cells) | [electronics_pod.stl](../hardware/cad/generated/electronics_pod.stl), [coupon_battery_holder.stl](../hardware/cad/generated/coupon_battery_holder.stl) | **nominal AA envelope; loaded holder height pending**. The selected K-KJ17MCA4BA kit includes four cells and a charger. Charge and replace matched cells together; do not buy four kits. |
| Panasonic BQ-CC17 external charger (K-KJ17MCA4BA kit) | Outside enclosure / shared consumable | **outside enclosure**. One shared kit provides a charger and the first four cells. A second actuator needs four additional cells, not a second charger. |
| Westfield WF52650 M2×6 nylon cheese-head screws | [electronics_pod.stl](../hardware/cad/generated/electronics_pod.stl), [coupon_pico_mount.stl](../hardware/cad/generated/coupon_pico_mount.stl) | **nominal interface check; physical assembly pending**. Nominal head Ø3.8×1.3 mm. Pre-tap printed Ø1.6 mm pilots M2×0.4 using a hand tap. Nylon screws are not self-tapping. |
| Bambu AA030 M2.5x8 SHCS | [electronics_pod.stl](../hardware/cad/generated/electronics_pod.stl), [retainer_proto.stl](../hardware/cad/generated/retainer_proto.stl), [retainer_regulator.stl](../hardware/cad/generated/retainer_regulator.stl), [retainer_master.stl](../hardware/cad/generated/retainer_master.stl), [retainer_servo_gate.stl](../hardware/cad/generated/retainer_servo_gate.stl) | **nominal interface check; physical assembly pending**. Four screws per retainer. One 20-piece pack covers a device with four spares. |
| Bambu AA037 M3x8 SHCS | [electronics_pod.stl](../hardware/cad/generated/electronics_pod.stl), [electronics_lid.stl](../hardware/cad/generated/electronics_lid.stl) | **nominal interface check; physical assembly pending**. Lid attachment. Buy the smallest available pack covering four screws. |
| Bambu AA036 M3x6 SHCS | [electronics_pod.stl](../hardware/cad/generated/electronics_pod.stl), [docking_strap.stl](../hardware/cad/generated/docking_strap.stl), [1g_chassis.stl](../hardware/cad/generated/1g_chassis.stl), [2g_chassis.stl](../hardware/cad/generated/2g_chassis.stl) | **nominal interface check; physical assembly pending**. Two screws per docking strap. Buy the smallest available pack covering four screws. |
| M3x0.5 standard hex nuts: 5.5 mm AF, max 2.4 mm thick | [electronics_pod.stl](../hardware/cad/generated/electronics_pod.stl), [1g_chassis.stl](../hardware/cad/generated/1g_chassis.stl), [2g_chassis.stl](../hardware/cad/generated/2g_chassis.stl) | **nominal interface check; physical assembly pending**. Standard nonlocking nut no thicker than 2.4 mm. Printed pockets are 5.8 mm across flats. Select by dimensions as well as thread. |
| M2x0.4 x10mm A2 socket-head screws | [1g_chassis.stl](../hardware/cad/generated/1g_chassis.stl), [2g_chassis.stl](../hardware/cad/generated/2g_chassis.stl), [coupon_servo_ear_mount.stl](../hardware/cad/generated/coupon_servo_ear_mount.stl) | **nominal interface check; physical assembly pending**. Two per servo. Actual ear thickness and washers determine thread engagement; test on the mounting coupon. |
| M2x0.4 standard hex nuts: 4 mm AF, max 1.6 mm thick | [1g_chassis.stl](../hardware/cad/generated/1g_chassis.stl), [2g_chassis.stl](../hardware/cad/generated/2g_chassis.stl), [coupon_servo_ear_mount.stl](../hardware/cad/generated/coupon_servo_ear_mount.stl) | **nominal interface check; physical assembly pending**. Two per servo. Printed nut pockets are 4.2 mm across flats; verify the actual nut height and slot fit. |
| M2 flat washers: 2.2 mm ID, 5 mm OD, 0.3 mm thick | [1g_chassis.stl](../hardware/cad/generated/1g_chassis.stl), [2g_chassis.stl](../hardware/cad/generated/2g_chassis.stl), [coupon_servo_ear_mount.stl](../hardware/cad/generated/coupon_servo_ear_mount.stl) | **nominal interface check; physical assembly pending**. Two per servo. Confirm selected 5 mm outer diameter washers clear the actual ears. |
| Panduit PLT2M-C 2.5mm x~200mm cable ties | [electronics_pod.stl](../hardware/cad/generated/electronics_pod.stl) | **nominal interface check; physical assembly pending**. Two battery-holder straps through 3.5×2.4 mm slot cross-sections. Buy the smallest pack covering two; trim tails. |
| 3M SJ5302 urethane bumper: Ø7.9×2.2 mm | [1g_servo1_yoke.stl](../hardware/cad/generated/1g_servo1_yoke.stl), [2g_servo1_yoke.stl](../hardware/cad/generated/2g_servo1_yoke.stl), [2g_servo2_yoke.stl](../hardware/cad/generated/2g_servo2_yoke.stl) | **nominal interface check; physical assembly pending**. One bumper at each yoke end. Manufacturer dimensions are modeled. These contacts do not provide calibrated force limiting. |
| External support for textured wall: selection unresolved | [1g_chassis.stl](../hardware/cad/generated/1g_chassis.stl), [2g_chassis.stl](../hardware/cad/generated/2g_chassis.stl), [electronics_pod.stl](../hardware/cad/generated/electronics_pod.stl) | **BLOCKED: photographed wall excludes selected Command strips**. Do not buy Command 17201 strips for the photographed textured wall. Four pairs are a conditional option only on an approved smooth surface. An external support arrangement for this wall is still unresolved. |
| PETG filament | Outside enclosure / shared consumable | **slicer and print calibration required**. Use existing suitable PETG. Consumption depends on slicer infill, supports and brims, and has not been estimated from G-code. PLA is acceptable for fit coupons. |
| M2x0.4 hand tap and holder | Outside enclosure / shared consumable | **outside enclosure**. Use an M2×0.4 tap on the Pico coupon and then the printed mounting posts. Do not force nylon screws into untapped pilots. Keep the back wall closed. |
| Digital calipers and multimeter | Outside enclosure / shared consumable | **outside enclosure**. Calipers and a multimeter are needed before final printing and power-up; no particular brand is required. Also use a wire stripper/cutter, solder, flux, iron, slotted driver and 1.5/2/2.5 mm hex keys. |

## Explicit limits

- Both assembled gang variants tested at neutral; complete dynamic motion is not collision solved.
- Nominal component geometry is not proof of manufacturing tolerance, actual servo/horn fit, all wire routing, thermal performance, or printed thread strength.
- Full electrical board pad routing and complete wire harness placement are not modeled.
- Screw threads and all fastener bodies are not modeled; selected interfaces use nominal hole/depth checks.
- Current textured-wall mounting and exact horn-to-yoke fasteners remain unresolved.

The illustrated regulator/protoboard internals and generic connector bodies are space models; they are not replacement manufacturing drawings. The servo geometry is a TowerPro reference with several labelled unsourced interface dimensions. Current physical fit remains **unverified** even when every automated row reads PASS.

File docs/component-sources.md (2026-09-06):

# Component geometry and source confidence

**Historical reference — earlier Pico design; not the current build instructions.** For the current ESP32-S2 Mini POC, start with [S2 wiring](s2-aa-poc.md), [S2 firmware](s2-firmware.md) and the [current BOM](../BOM.md).

The Pico W reference now uses **Raspberry Pi's own 3D assembly**, rather than an invented board-shaped box. The repository includes the original STEP archive plus a Blender-importable OBJ with 11 named parts. An MG90S label, however, does not identify one guaranteed mechanical drawing: the original manufacturer's page omits several dimensions needed for a tight mount, and other manufacturers sell different MG90S geometries.

Machine-readable values, source IDs, unresolved measurements, and checksums are in [board-servo.json](../hardware/components/board-servo.json). Final physical-fit approval still requires matching the actual purchased board, servo, solder joints and power components.

## Pico W and Pico 2 W mechanical interface

Both current manufacturer drawings were visually checked: **Pico W datasheet release 7** and **Pico 2 W datasheet release 2**, both built 03 July 2026, printed page 6, Figure 3. Their board outline, mounting pattern, and main header grid match. The components mounted on those boards differ. [Pico W datasheet](https://datasheets.raspberrypi.com/picow/pico-w-datasheet.pdf), [Pico 2 W datasheet](https://datasheets.raspberrypi.com/picow/pico-2-w-datasheet.pdf).

For this table, the origin is the center of the PCB's **top plane**, x crosses its short dimension, y points toward USB, and z points away from the PCB toward the components. Dimensions are in millimetres. The PCB occupies x = −10.5…10.5, y = −25.5…25.5, and nominally z = −1…0.

| Feature | Confirmed nominal geometry | Evidence and use |
| --- | --- | --- |
| PCB | 21 wide × 51 long × 1 thick | Mechanical specification text; allow manufacturing and print tolerance |
| Mounting holes | Four, diameter 2.1 ± 0.05 | Manufacturer text; use suitable M2 hardware rather than enlarging the PCB holes |
| Hole centers | (−5.7, −23.5), (+5.7, −23.5), (−5.7, +23.5), (+5.7, +23.5) | Derived from Figure 3's 11.4 transverse spacing and 2 mm offset at each short end |
| Main header rows | x = ±8.89 | Figure 3: 17.78 mm row spacing |
| Main header positions | y = 24.13 − 2.54i, i = 0…19 | Twenty per row; 2.54 pitch and 48.26 first-to-last span, centered on board |
| Header drill | Diameter 1 | Figure 3; not the protruding header-pin length |
| Micro-USB shell width | 8 | Figure 3; cable plug is a separate, larger envelope |
| Micro-USB overhang | 1.3 typical beyond USB board edge | Figure 3; original W source CAD measures about 1.35 |
| Antenna carrier cutout | 14 wide × 9 deep at the non-USB end | Section 2.2.1 and Figure 7; center it about x = 0 and reserve y = −25.5…−16.5 under the board |
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

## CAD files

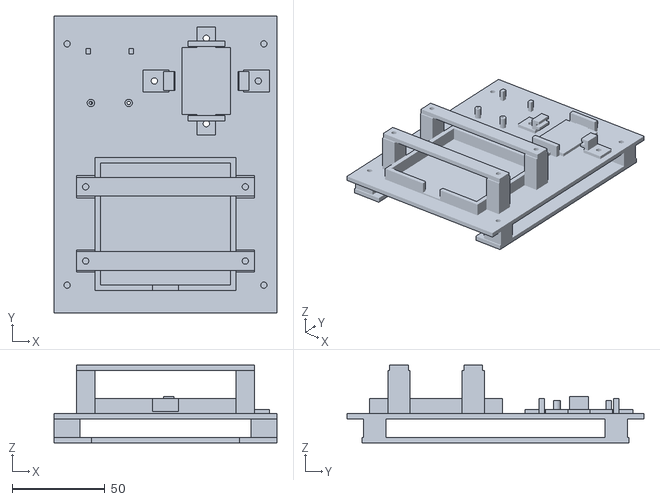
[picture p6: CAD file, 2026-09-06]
hardware/cad/electronics-retention-v4/generated/electronics-wall-mount-ASSEMBLED-v4-CONCEPT.stl
120.0 x 160.0 x 42.0

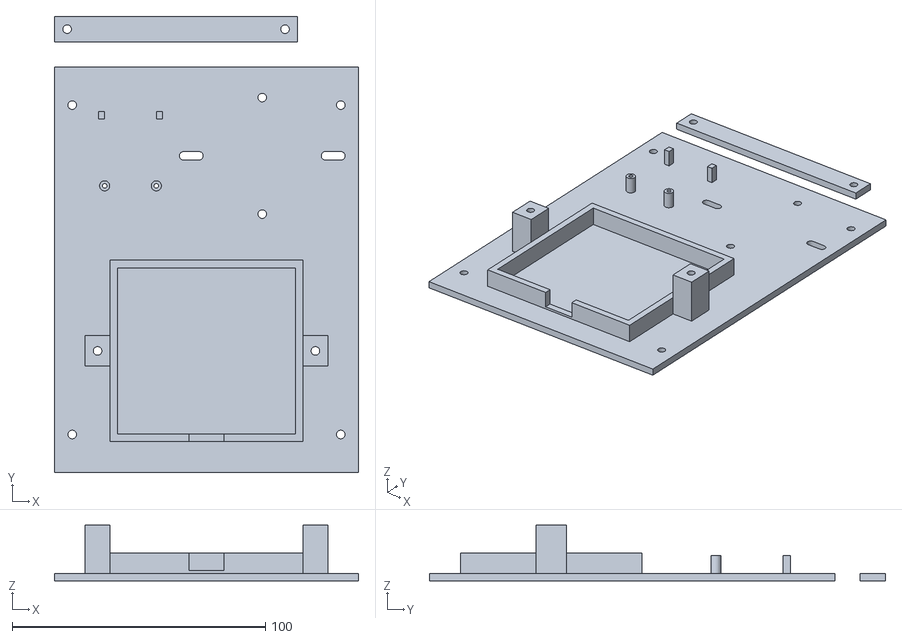
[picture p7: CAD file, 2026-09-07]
hardware/cad/battery-retention-v7/generated/battery-retention-v7-NEW-CARRIER-AND-BAR.stl
120.0 x 180.0 x 22.0

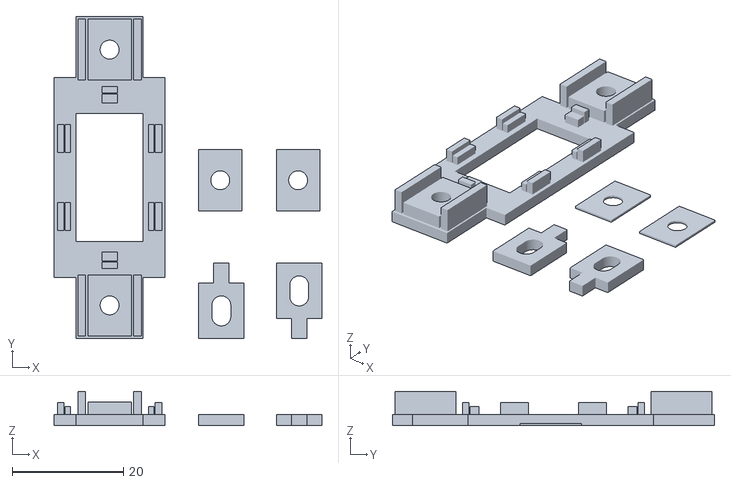
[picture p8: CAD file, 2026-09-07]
hardware/cad/booster-retention-v1/generated/booster-retention-v1-ALL-FIVE-FIT-TEST.stl
48.2 x 58.0 x 6.20

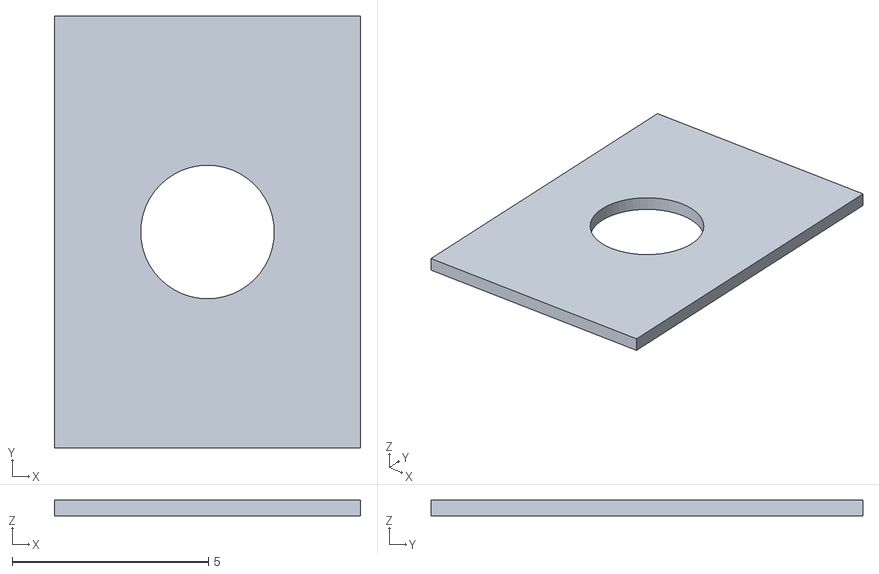
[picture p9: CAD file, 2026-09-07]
hardware/cad/booster-retention-v1/generated/stl-fit-test/04_lower_height_shim_0p4-FIT-TEST.stl
7.80 x 11.0 x 0.4

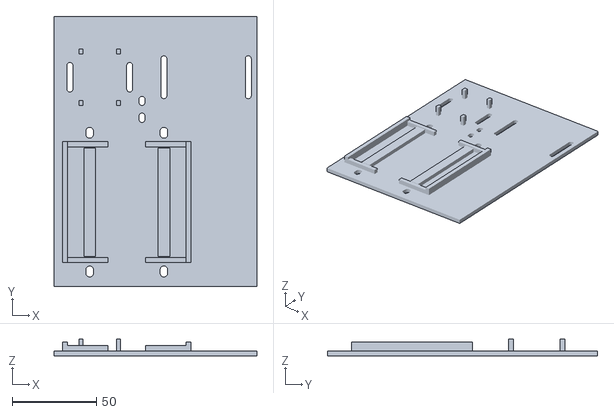
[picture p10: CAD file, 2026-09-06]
hardware/cad/electronics-carrier-v2/generated/electronics_carrier_v2_DRAFT_FIT_TEST.stl
120.0 x 160.0 x 10.0

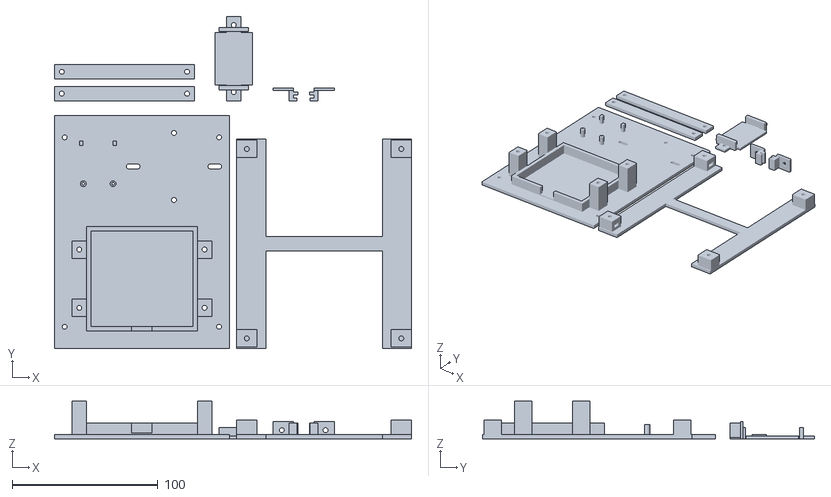
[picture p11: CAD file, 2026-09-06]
hardware/cad/electronics-retention-v4/generated/electronics-wall-mount-ALL-PIECES-v4-CONCEPT.stl
245.0 x 228.0 x 26.0

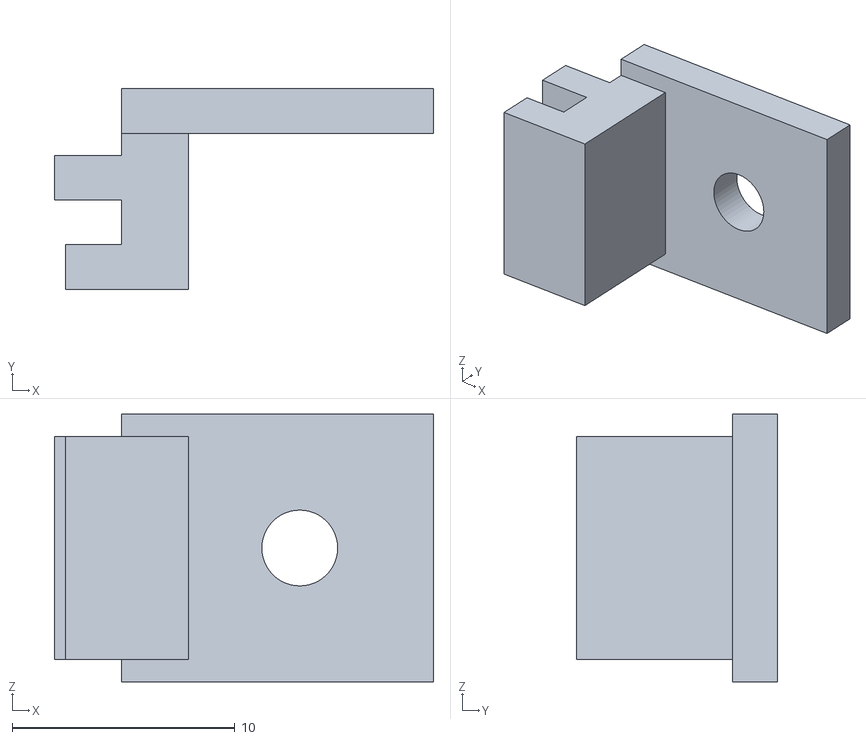
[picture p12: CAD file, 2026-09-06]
hardware/cad/electronics-retention-v4/generated/stl-concept/06_converter_jaw_right_CONCEPT.stl
17.0 x 9.00 x 12.0

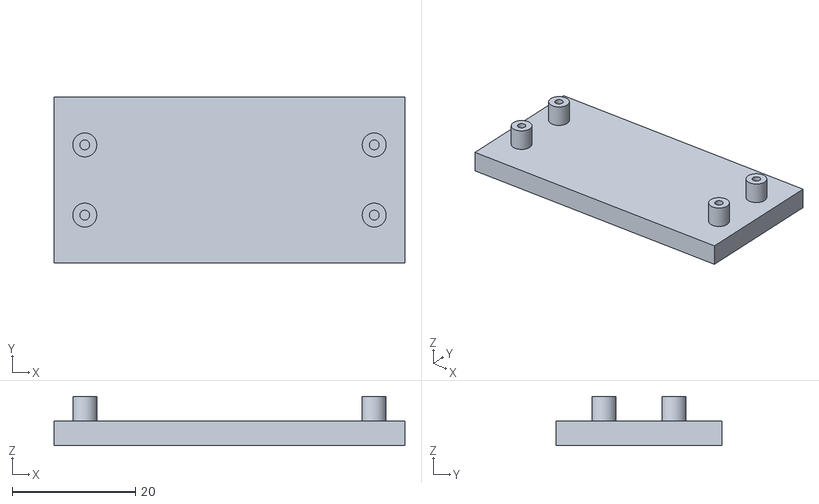
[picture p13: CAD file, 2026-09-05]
hardware/cad/generated/coupon_pico_mount.stl
57.0 x 27.0 x 8.00

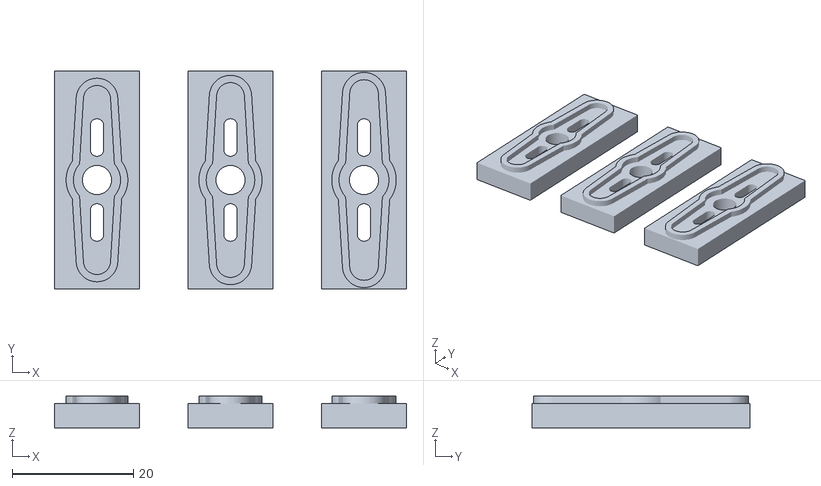
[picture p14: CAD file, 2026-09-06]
hardware/cad/horn-pocket/generated/horn-fit-coupons-ALL-THREE-PHOTO-ESTIMATE.stl
58.0 x 36.0 x 5.20

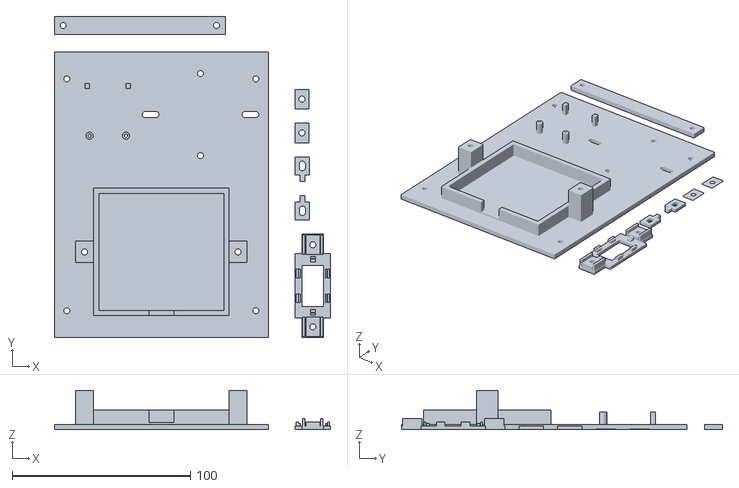
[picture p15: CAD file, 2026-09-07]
hardware/cad/revision-print-v8/generated/auto-switch-ALL-NEW-PIECES-v8-FIT-TEST.stl
155.0 x 180.0 x 22.0

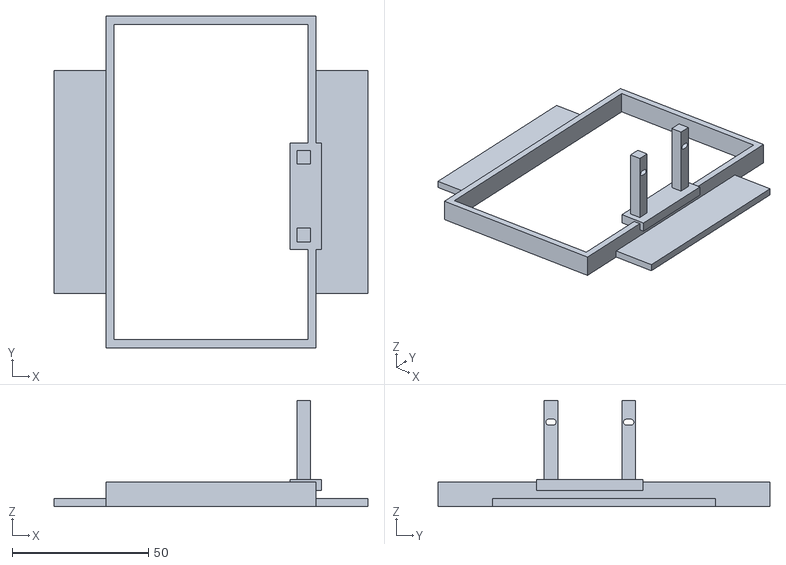
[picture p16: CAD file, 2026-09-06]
hardware/cad/s2-aa-poc/generated/02_wall_chassis.stl
115.2 x 121.7 x 39.0

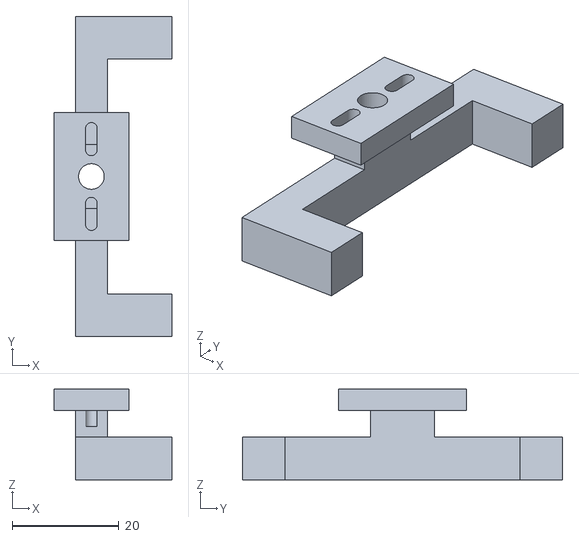
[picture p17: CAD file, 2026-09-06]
hardware/cad/servo-command/generated/03_factory_horn_paddle.stl
22.1 x 60.0 x 17.0

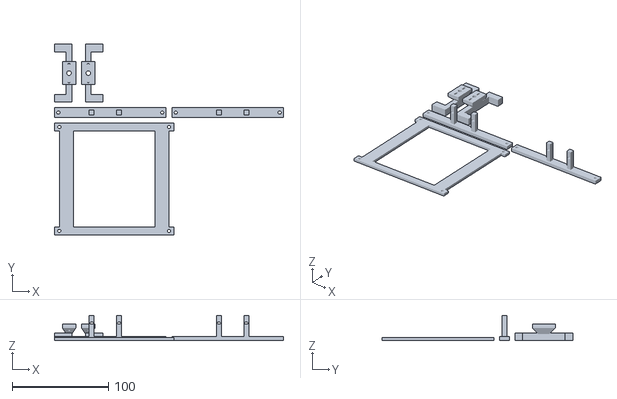
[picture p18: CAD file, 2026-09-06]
hardware/cad/servo-multi/generated/double/double-ALL-PIECES-CONCEPT.stl
238.0 x 198.0 x 26.0

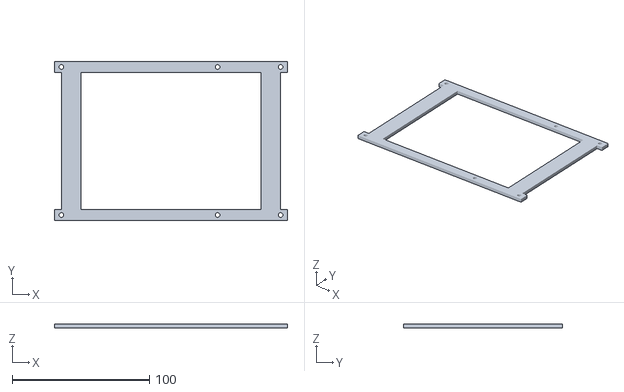
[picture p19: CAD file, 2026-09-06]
hardware/cad/servo-multi/generated/triple/01_frame.stl
170.0 x 116.0 x 3.00

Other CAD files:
hardware/cad/revision-print-v8/generated/parts/07_05_upper_height_shim_0p4-FIT-TEST.stl
hardware/cad/battery-retention-v7/generated/02_FLAT-CROSSBAR-v7.stl
hardware/cad/booster-retention-v1/generated/stl-fit-test/03_upper_end_finger-FIT-TEST.stl
hardware/cad/electronics-carrier-v2/generated/s2_corner_support_coupon.stl
hardware/cad/battery-retention-v5/generated/01_LEFT_fixed_battery_edge_rail.stl
hardware/cad/battery-retention-v5/generated/02_LEFT_captured_pressure_shoe.stl
hardware/cad/battery-retention-v5/generated/03_RIGHT_fixed_battery_edge_rail.stl
hardware/cad/battery-retention-v5/generated/04_RIGHT_captured_pressure_shoe.stl
hardware/cad/battery-retention-v5/generated/05_cradle_shim_0.4mm.stl
hardware/cad/battery-retention-v5/generated/06_cradle_shim_0.6mm.stl
hardware/cad/battery-retention-v5/generated/07_cradle_shim_0.8mm.stl
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

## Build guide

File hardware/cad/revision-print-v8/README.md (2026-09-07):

# All revised pieces: V8 fit-test print

[Download the combined STL](generated/auto-switch-ALL-NEW-PIECES-v8-FIT-TEST.stl).

This combines the V7 battery carrier and its centered flat bar with the selected option C booster adapter, two retaining fingers and two seat shims. These are separate pieces arranged together on one Bambu A1 bed, not an assembled solid. Reuse the existing separate Command-strip wall bracket. Electronic reference objects and metal fasteners are excluded.

**The booster is a fit test.** Its PCB is assumed to be 16 × 30 × 1.2 mm; the thickness and underside have not been measured. Its end-center support/contact areas must be clear of components, pads and solder. The battery bar has zero designed vertical gap against a seller-nominal 19 mm case; the cradle retains its previous lateral clearance. These exports do not establish physical snugness.

Import in millimeters at 100% scale. All parts are oriented flat on the bed. Use by-layer printing; the layout is not checked for sequential/by-object printing. Keep the two small shims: they set the booster finger height. Printed fit and material tolerance still need checking against the unpowered board. If a finger presses on a component, solder or bends the board, do not tighten it to force a fit.

Fasteners: two M3×30 screws and two M3 nuts for the battery bar. See the [booster fit-test instructions](../booster-retention-v1/README.md) for its verified modeled screw stack and assembly. Existing ESP32 attachment remains two M1.6×16 screws and nuts.

The manifest records source hashes and each packed part. `independent-stl-audit.json` checks closed solids, contents, spacing, bed contact and A1 bounds. These are digital geometry checks, not a physical fit approval.

```sh
python3 hardware/cad/revision-print-v8/combine.py
python3 hardware/cad/electronics-retention-v4/verify_stl_independent.py hardware/cad/revision-print-v8/generated/parts hardware/cad/revision-print-v8/generated/auto-switch-ALL-NEW-PIECES-v8-FIT-TEST.stl
/Applications/Blender.app/Contents/MacOS/Blender -b --factory-startup --python hardware/cad/revision-print-v8/render_layout.py
```

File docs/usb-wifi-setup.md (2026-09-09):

# USB Wi-Fi setup companion

Normal use and wireless application updates both use your saved home Wi-Fi.
The ESP32 never creates a setup or recovery access point. To join a different
network, connect USB and save credentials through the local companion.

[Download the Mac app](https://github.com/eoinest/auto-switch/releases/tag/companion-v0.1.0)
for Apple Silicon/macOS 15+. It bundles Python and the USB tools; unzip and open
**Auto Switch Setup.app**. This preview is not Apple-notarized and may need manual
first-launch approval. The command below remains available for running from source.

**Status:** implementation and host tests complete; installation and saving to
the physical S2 Mini still need testing. The board was not detected during this change.

## The power switch

Put a dedicated SPST switch only in the **booster VOUT → ESP32 VBUS** wire.
The servo retains its own connection to booster VOUT. No positive breadboard
rail or other wire may bypass the switch. Keep ground common.

```text
 FOUR-AA HOLDER                    BUCK-BOOST, measured 5.0 V
 + --[holder ON/OFF]--------------> VIN
 - ------------------------------> GND
                                   VOUT hole A --[S2 ISOLATION]--> S2 VBUS/5V
                                   VOUT hole B ------------------> Servo +
                                   GND hole A -------------------> S2 GND
                                   GND hole B -------------------> Servo GND

                                                    S2 GPIO16 ---> Servo signal
 Mac USB ------------------------------------------> S2 USB-C
           Connect USB only with S2 ISOLATION open/OFF.
```

The VOUT holes are duplicate connections to the same regulated supply. The
[official S2 schematic](https://www.wemos.cc/en/latest/_static/files/sch_s2_mini_v1.0.0.pdf)
connects the USB 5 V pin and VBUS pad directly. The new switch separates that
shared board supply from the booster. Switching off the holder alone does not.

Use an insulated switch and joints, with a DC rating suitable for the board's
supply current. The switch is not connected to a GPIO. With batteries removed
and USB unplugged, verify the new switch breaks continuity between booster
VOUT and S2 VBUS when OFF, and connects them when ON.

## Save Wi-Fi over USB

1. Turn the battery holder OFF and the S2 isolation switch OFF.
2. Unplug the servo's three-wire connector, then plug the S2 into the Mac by USB.
   The isolation switch separates positive power, but not GPIO16; unplugging the
   servo avoids sending a signal into an unpowered servo during setup.
3. From the repository root, launch the companion:

   ```sh
   python3 companion/server.py
   ```

4. Open the local address shown by the companion, select the connected board,
   enter the network name/password, and save. It reads the existing device
   configuration, changes only the Wi-Fi credentials, and restarts the S2.
5. Unplug USB. With both switches OFF, reconnect the servo. Turn the S2 isolation
   switch ON and then the holder ON for normal battery operation.
6. On a phone on that same Wi-Fi, open **http://auto-switch.local/**.

The companion configures an already-installed MicroPython application; it does
not flash firmware or erase the board. If the device configuration cannot be
read, it stops instead of replacing it with defaults. Saved calibration and
other configuration remain intact. An incorrect Wi-Fi password can be corrected
by repeating USB setup.

The companion listens only on the Mac's loopback address. Passwords are not put
in URLs, subprocess arguments, logs or Git. Private temporary configuration files
have owner-only permissions and are deleted after the operation. Do not copy
device config or flash dumps into tracked files.

## Updates after connection

Once connected to home Wi-Fi, application updates remain wireless: hold BOOT/0
for three seconds after startup, release it, and open
**http://auto-switch.local/update**. Battery wiring stays connected and USB stays
unplugged. See [wireless update instructions](wireless-updates.md).

No new enclosure switch cutout has been modeled in this change. Position the
isolation switch where it remains accessible; the old printed carriers are
unchanged.

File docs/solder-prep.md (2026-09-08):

# Solder preparation — headerless S2 Mini and received XL63070

**Latest revision:** the [USB setup wiring map](usb-wifi-setup.md) adds a dedicated switch in the booster → ESP32 VBUS branch. Earlier images below do not yet depict that switch.

[One-page diagram](../hardware/wiring/solder-prep/solder-prep.png) · [Scalable SVG](../hardware/wiring/solder-prep/solder-prep.svg) · [Latest three-critic wiring review](reviews/wiring-decision-2026-09-08.md)

## Seven terminal groups to prepare

Disconnect USB and remove batteries before soldering. Apply a small amount of solder to the chosen pads and stripped wire ends; avoid large blobs, loose strands and bridges to neighboring pads. For the illustrated breadboard arrangement, use one convenient hole from each converter terminal group. For direct wiring, use both VOUT holes for separate S2/servo power leads and both output GND holes for their separate returns; verify same-group continuity unpowered. These are duplicate connections to one supply, not extra current capacity. Keep the two bare center strips at the converter’s short ends free for the mounting fingers.

### ESP32-S2 Mini: three pads

View the component side with USB pointing down. On the **outermost right-hand pad row**, the bottom three pads are:

| Position | Pad | Wire goes to |
|---|---|---|
| Bottom | VBUS / 5V | Verified 5 V positive rail |
| One above bottom | GND | Ground rail |
| Two above bottom | 16 / GPIO16 | Servo signal, usually orange/yellow |

Use the actual printed labels as the final check. The inner row has different signals, and a view from the underside is mirrored. **Do not use 3V3, GPIO15 or GPIO17 in place of these pads.** The official [WEMOS pinout](https://www.wemos.cc/en/latest/_static/boards/s2_mini_v1.0.0_4_16x9.jpg) establishes these locations for LOLIN S2 Mini V1.0.0; compare clone labels before soldering. The firmware’s S2 profile uses GPIO16 at 50 Hz.

### Received XL63070: four terminal groups

View the component side like your photo: inductor on the left and the XL63070 label at the bottom.

| Position | Pad group | Wire goes to |
|---|---|---|
| Bottom left | VIN | Switched holder red (+), about 6 V nominal from four alkaline AAs |
| Bottom right | GND | Holder black (−) |
| Top left | VOUT | Shared positive rail, **after measuring about 5.0 V** |
| Top right | GND | Shared ground rail |

The two GND groups are the same electrical ground. Duplicate holes within a terminal group share a net and can accept separate wires to the two loads. **Do not pre-tin EN, PS, ADJ or the voltage-selection links.** Leave the factory configuration unchanged during this preparation; verify its output separately.

## Whole circuit

```text
4 × AA alkaline cells in switched holder
  red (+) ── built-in switch ── VIN  ┌──────────┐ VOUT ── verified 5 V ──┬── S2 VBUS/5V
 black (−) ─────────────────── GND  │ XL63070  │                       └── Servo red (+)
                                    └──────────┘ GND ── ground rail ──┬── S2 GND
                                                                      └── Servo brown/black
                                                           S2 GPIO16 ──── Servo signal
```

The holder red lead is already switched; no second switch is required. The S2 and servo draw power in parallel. Servo power does not flow through an ESP32 GPIO or its 3.3 V regulator. On a breadboard, check the actual power-rail splits with power disconnected and bridge any split used by these connections. Keep the power leads short; the [breadboard checklist](../hardware/wiring/s2-aa-poc/connections.csv) gives the existing illustrated hole positions.

## Before power-up

1. With batteries removed, inspect solder joints and check for a hard short between power and ground. Capacitors may cause a brief continuity response; investigate a sustained near-zero resistance. Continuity mode is for unpowered wiring.
2. Leave the S2 and servo disconnected. Install cells and measure VOUT against GND using DC volts mode, black lead in COM and red lead in V/Ω. It must be about 5.0 V, not raw battery voltage or another jumper setting.
3. Switch off before connecting the S2, then test its Wi-Fi. Next test the servo unloaded with small movements before adding switch load. Stop if the board resets, the servo jitters or contacts become hot; those symptoms mean the power path needs attention.
4. For USB programming, disconnect all three S2 harness leads from the breadboard first, and keep their exposed ends isolated. The [S2 schematic](https://www.wemos.cc/en/latest/_static/files/sch_s2_mini_v1.0.0.pdf) directly ties VBUS to USB power: switching the battery holder off alone does not isolate USB from the servo/converter rail.

No firmware was enabled or flashed as part of this diagram update. The actual battery-and-servo circuit still needs these bench tests.

## USB live testing is a separate wiring mode

The all-three-leads disconnect above is the simple isolated programming procedure. For live servo testing over USB, physically remove and insulate **only the booster-to-S2 VBUS power lead**, ensure no breadboard positive rail bypasses it, and retain the common ground. USB then powers the S2; the battery/booster powers the servo. Keep GPIO16 disconnected until both devices are powered; disconnect it before either supply is switched off, unless a verified inactive-signal procedure is in use. Do not send commands to an unpowered servo. See the [mode table and complete direct-wiring map](reviews/wiring-decision-2026-09-08.md).

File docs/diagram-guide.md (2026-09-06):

# Read the Auto Switch diagrams

**Historical reference — earlier Pico design; not the current build instructions.** For the current ESP32-S2 Mini POC, start with [S2 wiring](s2-aa-poc.md), [S2 firmware](s2-firmware.md) and the [current BOM](../BOM.md).

Start with the [complete connection map](../hardware/wiring/connection-map.svg): one continuous drawing with every component, all supply and signal wires, and a shared ground return. The learning site opens this map first and provides fit, zoom and full-screen controls.

The [power explorer](../hardware/wiring/power-map.svg) remains an optional teaching view. Follow the red supply branch **into VSYS pad 39**, across the boundary of the Pico board, through its onboard regulator, and into the chip at 3.3 V. This is the missing link between the battery assembly and the running Pico.

The connection map draws all 46 external terminals from [harness.json](../hardware/wiring/harness.json). Automated geometry checks verify that each terminal touches its assigned wire and that every named net is connected within the drawing. Labels identify wires; you do not need to jump between repeated labels or separate panels. Use the [assembly instructions](wiring.md) and [shopping list](shopping-list.md) alongside it. These diagrams are functional electrical drawings, not an exact per-hole soldering layout or a substitute for continuity checks.

## Two supplies meet inside the Pico

The external branch is holder positive → fuse → RCY disconnect → master switch → external 5 V regulator → **external D1** → VSYS. The Pico's own regulator then generates 3.3 V. The external diode's striped cathode faces VSYS.

The USB branch is USB connector → **VBUS** → **onboard diode** → the same VSYS junction. The onboard diode is already installed on the Pico; do not buy or solder another part for that symbol. The diagram calls our added diode “external D1” to distinguish it from the Pico schematic's own reference designators. VBUS is the USB supply connection, not a Pico-generated 5 V regulator output. This topology and the external-diode arrangement follow the [official Pico W power documentation, sections 3.4–3.5](https://datasheets.raspberrypi.com/picow/pico-w-datasheet.pdf).

With USB alone, the Pico works and the motor rail stays off. With the battery master on, the external branch can power the Pico and the servo gate's input. With both supplies, the branch with the higher voltage after its diode normally supplies VSYS; closely matched sources can share current. Neither diode is an ideal zero-drop valve, and the voltage drop depends on current and temperature. A teaching simulator can show *available paths* without predicting exact current sharing.

Direct soldering to a headerless Pico keeps the same physical **pad numbers**. “GP15” means a GPIO function; “20” identifies its physical edge pad. Pad 39 is VSYS; pad 38 is ground. Pad 40 VBUS and pad 36 3V3 OUT receive no external harness wire in this build. USB is still plugged into the board's USB connector for programming. [Official pinouts](https://www.raspberrypi.com/documentation/microcontrollers/pico-series.html).

## The servo uses a different branch

Regulated 5 V also feeds the **VIN** of the servo's Pololu 2810 LV gate. Its VOUT feeds the servo supply wire. The Pico drives the gate's **ON** input with GP15, using 3.3 V logic. This signal controls a MOSFET; motor current flows through the MOSFET's power terminals, not through GP15. The gate's physical slider must remain OFF so that it does not override software control. The manufacturer specifies that ON above approximately 1 V enables the gate. [Pololu 2810 operation](https://www.pololu.com/product/2810).

The 5 V regulator is a different device with a different job. It converts the battery's varying voltage into a nominal 5 V supply; it cannot provide unlimited motor current. Leave its ENABLE input unconnected in this design. [Pololu S18V20F5](https://www.pololu.com/product/2574).

GP16 and GP17 carry servo position commands through their separate 1 kΩ resistors. Turning off this PWM signal does not physically disconnect the servo's power. Turning off the gate does. Keep the signals inactive when motor power is off; a powered signal can otherwise feed a small unintended path through a servo's input electronics.

## Grounds, junctions and symbols

- **GND is one connected net:** battery negative, USB ground, Pico, regulator, both switch modules, servos and passive returns share it. Every external ground wire is drawn back to one continuous bus along the bottom. Ground is the circuit's reference voltage and return path; it need not be connected to the earth or the wall.
- **Motor return:** connect it at the power assembly, not by routing it through the Pico. The heavy supply line and its return together form the current loop.
- **Named nets:** every appearance of `5V`, for example, refers to the same connected conductor. `5V` and `SERVO_5V` are different nets separated by the gate. `PACK_SW` is varying raw battery voltage after the master, not regulated 5 V.
- **Filled dot:** wires join at that point. A white gap at an unrelated crossing shows that the wires do not join. All same-net branches are continuous and marked with junction dots.
- **Resistor rectangle:** limits current or helps set a voltage. Value is in ohms (Ω); kΩ means thousands of ohms.
- **Capacitor plates:** store a little electrical energy. C1 is polarized: its positive terminal faces 5 V and its negative stripe faces ground. C_ADC is a non-polar ceramic capacitor.
- **Diode bar:** marks the cathode. On our two external 1N5819 parts, the physical stripe identifies that end. D2's cathode faces the switched servo supply; its anode faces ground.

D2 addresses negative output transients; C1 buffers the input supply; R_BLEED discharges the servo rail after switching off. These do not guarantee a noise-free system or make an undersized supply adequate. Their roles follow the switch manufacturer's [transient-protection guidance](https://www.pololu.com/product/2810). The actual servo, wire length and power supply still need bench measurements.

## Battery sensing

The upper 100 kΩ resistor starts at **PACK_SW**, before the 5 V regulator. Its lower end joins GP26/ADC0, the 47 kΩ lower resistor, and the 100 nF filter capacitor. The resistor and capacitor's other terminals connect to ground. The nominal relationship is:

`V_ADC = V_PACK_SW × 47 / (100 + 47)`

At a 4.8 V pack, that gives about 1.53 V. Sensing the regulated 5 V line would mostly tell you that the regulator still works, rather than reveal the battery's changing voltage. A voltage reading is not a precise NiMH charge percentage.

## Interactive integration

`tools/render_wiring.py` regenerates both SVGs without external libraries. `tools/continuous_wiring.py` lays out the complete circuit. Visible terminal circles carry `data-terminal` identifiers, while polylines carry `data-wire` net names and machine-checkable points; tests compare these with the harness. This checks drawn connectivity rather than relying only on text labels. The power map has stable group IDs:

| ID | Meaning |
| --- | --- |
| `path-battery` | Holder, fuse, connector and incoming master supply; available while battery is connected |
| `path-pack-sw` | Master output wire and PACK_SW label; available only when battery is connected and master is on |
| `path-regulated` | External regulator and regulated 5 V branch |
| `path-pico-external` | Added diode and incoming VSYS supply |
| `path-usb` | USB, VBUS and onboard USB diode |
| `path-vsys` | Shared VSYS and onboard regulator |
| `path-3v3` | Pico chip's regulated supply |
| `path-motor-input` | Gate input and gate module |
| `path-motor-output` | Switched rail and servo(s) |
| `path-ground` | Common ground reference and return paths |
| `path-control` | GP15 control signal |
| `path-pwm` | GP16 / GP17 position command signals |
| `path-adc` | Battery measurement network |

The CSS class `is-off` dims a group. Major components have `data-part` attributes for click-to-explain integration. These IDs distinguish supply availability from commanded motion: a USB-powered Pico can drive GP15 even when no battery supply exists for the motor. A working motor path requires both battery/regulator power and an enabled gate. Ground remains the shared reference, rather than becoming “off” when its voltage is zero.

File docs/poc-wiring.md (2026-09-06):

# Earlier Pico POC: one servo, switched AA holder, breadboard rails

**Historical reference — earlier Pico design; not the current build instructions.** For the current ESP32-S2 Mini POC, start with [S2 wiring](s2-aa-poc.md), [S2 firmware](s2-firmware.md) and the [current BOM](../BOM.md).

Decision recorded 2026-09-05. This was the earlier Pico proof-of-concept wiring plan: use existing materials where suitable, one Pico W / Pico 2 W and one MG90S. The earlier illustrated WAGO assembly and its shopping budget are reference designs, not the shopping requirements for this POC.

[Download the plain ASCII map](poc-wiring.txt).

```text
ONE-SERVO AA BREADBOARD POC -- conceptual wiring, not exact hole placement

  4 x AA NiMH in a holder with a built-in ON/OFF switch
  (battery voltage varies; this is NOT a fixed 5 V source)

  Holder RED (+, switched) ---- F1 fuse ----> REG VIN
  Holder BLACK (-) ------------------------> GND rail

                 +---------------------------+
                 | REG: fixed 5 V buck-boost  |
                 | (e.g. existing S18V20F5)   |
                 |                           |
                 | VIN   GND           VOUT  |
                 +--------|--------------|---+
                          |              |
                          v              v
                       GND rail       +5 V rail

  BREADBOARD +5 V RAIL ================================================
                              |                         |
                              |                         +----> MG90S RED (+)
                              |
                              +---- D1 Schottky ----> Pico VSYS (pin 39)
                                    anode -> cathode       |
                                             stripe       v
                                                  onboard regulator
                                                          |
                                                    Pico's 3.3 V

                                      Pico GP16 (pin 21) ----> MG90S SIGNAL
                                                               orange/yellow
                                                               (verify yours)

  BREADBOARD GND RAIL =================================================
                   |                 |                    |
                   |                 |                    +----> MG90S GND
                   |                 |                           brown/black
                   |                 +----> Pico GND (pin 38)
                   +----> REG GND and holder BLACK (-), as shown above

  Optional USB data cable -----------------------> Pico micro-USB socket
  VBUS (pin 40) and 3V3(OUT) (pin 36): no external wires in this POC.

  Every connection marked '+5 V rail' joins the SAME regulated supply.
  Every connection marked 'GND rail' joins the SAME ground return.
  D1's stripe faces the Pico. F1 is in the positive battery lead.
```

## Parts to check at home

| Part | Quantity | Role / selection |
| --- | ---: | --- |
| Headered Pico W / Pico 2 W | 1 | Existing board; GP16 controls one servo |
| MG90S and original lead/horn | 1 | Existing servo; confirm connector polarity |
| Matched rechargeable AA NiMH cells | 4 | Charge externally; do not substitute four alkalines on an unregulated Pico supply |
| Four-AA holder with ON/OFF switch | 1 | Replaces separate holder/master-switch/RCY assembly; integrated switch is in the positive lead. Confirm its wiring and current suitability. [Adafruit 830](https://www.adafruit.com/product/830) is a candidate with male jumper ends, not a load-verified selection. |
| Fixed 5 V buck-boost regulator | 1 | Still required by this plan. Previous selection: [Pololu S18V20F5 / 2574](https://www.pololu.com/product/2574). A breadboard adapter marked 5 V is not necessarily a buck-boost converter or capable of the servo load. |
| D1 Schottky diode | 1 | Previous choice 1N5819; stripe toward VSYS; retained to permit USB programming with the battery supply attached |
| F1 fuse and insulated inline holder | 1 each | Retained for battery wiring protection. Prior choice: 2 A time-delay, 5 x 20 mm. Rating remains provisional pending current/holder/wire checks; mount close to the holder's positive output. |
| Breadboard, 22 AWG solid-wire links, suitable male-ended leads | As needed | Power/ground rails distribute connections. Servo socket needs mating male pins; loose stranded wire does not plug directly into a breadboard. |
| Solder/heat-shrink and multimeter | Shared | Adapt switch/module leads if needed; check continuity and voltage |
| NiMH charger and USB data cable | Shared | Charge removed cells; program the Pico |

No WAGO blocks, separate RCY pair, GPIO-controlled power gate, or battery-sensing divider is required for this POC. A connector or extension may still be useful if needed to mate with the actual servo plug; reuse one if available.

The control signal is drawn **directly from GP16 to the servo**. The earlier 1 kOhm series resistor is optional protection, not fitted in this minimal map. The earlier 470 uF / 10 V capacitor is also omitted from the baseline; it can be added across the regulated rails (positive to +5 V, striped negative to GND) if transient behavior warrants it. Neither omission constitutes a verified hardware result.

## How to read and build this map

1. Keep the batteries and USB disconnected during wiring. Use one red rail for regulated +5 V and one blue rail for GND. The rail colours are labels, not power sources. Check rail continuity with the meter: some boards split rails halfway, and opposite-side rails are usually separate. Bridge any sections you actually use.
2. Put the switched holder output through the fuse into regulator VIN. Holder negative and regulator GND join the ground rail. Only regulator VOUT feeds the +5 V rail. Follow the actual board labels; the regulator box above is a logical symbol, not a terminal-location drawing. On S18V20F5, ENABLE stays unconnected.
3. With Pico and servo disconnected, power the supply and measure regulated +5 V against GND and the diode output against GND. The diode output must be within the board's VSYS limits (never above 5.5 V). Then switch off and disconnect the pack again before inserting the Pico or servo.
4. Connect VSYS through D1, Pico GND to ground, servo power/ground to their rails, and GP16 to servo signal. Place the regulator feed and servo power connections near each other; keep leads short and secure the holder/switch so movement does not pull on breadboard contacts.
5. Use [config.aa-demo.example.json](../firmware/config.aa-demo.example.json) with the [firmware guide](firmware.md): `hardware_profile: "aa-demo"`, `power_enable_pin: null`, battery sensing off, one GP16 channel. The channel starts disabled and uncalibrated. Calibrate with the servo unloaded, before attaching a switch-pressing mechanism.

## Scope and limits

This is an **initial supervised, unloaded-servo breadboard experiment**. The selected holder's switch current rating, actual breadboard/contact rating, and servo startup/loaded current are not established. Passing an unloaded test does not validate the wall-switch load. If contacts become warm, voltage collapses, the Pico resets, or the servo jitters, switch off and investigate the supply/connections; direct soldered power distribution is a fallback, not automatically a larger fuse.

The diagram retains the regulator, diode and fuse deliberately. Four AA cells do not produce fixed 5 V. Supplying battery power to VSYS through a Schottky diode follows [Raspberry Pi's power guidance, pages 16-17](https://datasheets.raspberrypi.com/rp2040/hardware-design-with-rp2040.pdf). With the holder switched off, attached USB can still power the Pico; it does not power the servo rail through D1. Disconnect both sources before rewiring.

No automatic low-battery cutoff is provided. Remove cells for external charging and switch off before depletion. No revised enclosure/STL fit or powered performance is claimed. The old $160 estimate included the WAGO build's retail packs and is not a price quote for this reduced POC; first inventory the parts above, especially the regulator, diode and fuse.

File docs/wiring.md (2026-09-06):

# Earlier Pico wiring: gated power circuit

**Historical reference — earlier Pico design; not the current build instructions.** For the current ESP32-S2 Mini POC, start with [S2 wiring](s2-aa-poc.md), [S2 firmware](s2-firmware.md) and the [current BOM](../BOM.md).

This is the assembly map for the headerless Pico revision. It replaces the first revision’s unspecified load-switch breakout with **two Pololu 2810 LV modules**: one master switch and one servo power gate. Component purchases and quantities are in the root [BOM](../BOM.md), with a searchable copy in the [learning module](../learn/index.html#parts). The Pico firmware pin assignments stay the same.

For a first bench build with your existing headered Pico, use the [hole-by-hole breadboard guide](breadboard.md). It implements the same circuit with the motor power harness beside the breadboard.

Start with the [interactive power map](../learn/index.html#power), which shows the on-board regulator and both supplies. The [diagram guide](diagram-guide.md) explains the symbols.

How power reaches the Pico

The [complete connection sheet](../hardware/wiring/connection-map.svg) includes every passive component and terminal.

The complete connection list is also machine-readable in [`hardware/wiring/harness.json`](../hardware/wiring/harness.json). This is a functional wiring plan, not a manufactured PCB or a bench-tested circuit. Use the installed boards’ **silkscreen labels**; a connector viewed from its mating face is mirrored relative to its solder face.

## What physically connects the batteries to the Pico

The **Pololu 1153 battery holder already contains the springs, contacts and two 6-inch, 24-AWG leads**. Insert four matched AA NiMH cells into it. No extra spring-contact adapter is required, and nothing is soldered to a battery cell. [Holder specification](https://www.pololu.com/product/1153).

Fit a fuse near its positive lead, followed by a detachable **JST RCY connector pair**. Use the purchased prewired mates to avoid needing a special crimp tool. The battery side must have recessed female **metal contacts** so exposed live pins cannot touch objects when unplugged. Verify actual contact geometry and red/black continuity; the plastic housing’s apparent gender can be misleading. The mating side leads to the master switch. [Female pigtail](https://www.pololu.com/product/2180), [male pigtail](https://www.pololu.com/product/2181).

The positive path is:

```text
holder red → fuse → RCY disconnect → master 2810 VIN
master 2810 VOUT → regulator VIN
regulator VOUT (5 V) → diode D1 → Pico VSYS
regulator VOUT (5 V) → servo-gate 2810 VIN → VOUT → servo power
```

Battery black, both modules’ GND pads, regulator GND, the Pico and servo grounds all share a ground net. Splice/terminate the motor ground on the power assembly; do not make motor current pass through the Pico board.

The current fitted assembly uses a **headerless Pico W**, mounted directly on printed posts with nylon screws. Solder the six low-current wires below to its named edge pads; one gang omits GP17. No PiCowBell or 40-pin socket carrier is required. Leave clearance under the PCB for solder joints and secure the insulated wires to the printed strain relief so the joints carry no cable tension. The existing headered Pico remains useful on the bench, but is not the board stack checked by the current STLs. Physical pin numbers identify the same pads with or without headers.

## Pico harness: six low-current connections

| Pico signal | Physical pin | Destination | Suggested color |
| --- | ---: | --- | --- |
| VSYS | 39 | D1 **striped cathode**; D1 anode connects to regulated 5 V | Red |
| GND | 38 | Common ground on power assembly | Black |
| GP15 | 20 | Servo gate’s **ON** input, plus 100 kΩ pulldown to GND | Yellow |
| GP16 | 21 | 1 kΩ series resistor → servo 0 signal | White |
| GP17 | 22 | 1 kΩ series resistor → servo 1 signal; omit for one gang | Orange |
| GP26 / ADC0 | 31 | Battery-divider midpoint | Blue |

These are **physical pin numbers plus GPIO names**, not interchangeable numbering systems. Do not connect the battery/servo rail to pin 36 (3V3 OUT) or pin 40 (VBUS). Only the Pico’s ordinary USB connector is used for programming; the diode arrangement permits USB and battery-powered VSYS to coexist without feeding the servo rail from USB. [Raspberry Pi hardware documentation](https://datasheets.raspberrypi.com/picow/pico-w-datasheet.pdf).

## Configure the two switch modules differently

### Can the servo take power from the Pico's 5 V pin?

**Yes, when USB powers the board:** physical pin 40, `VBUS`, exposes the USB supply (nominally 5 V). A servo can run from that pin if the USB source, cable and board power path can handle its startup and load current. That is different from powering a motor from a GPIO. `VBUS` is a pass-through supply connection, not a software-controlled or Pico-generated 5 V output. Feeding a battery into `VSYS` does not make 5 V appear on `VBUS`; the on-board regulator generates **3.3 V**, not 5 V. [Pico W datasheet, sections 3.4–3.5](https://datasheets.raspberrypi.com/picow/pico-w-datasheet.pdf).

The external servo gate serves a different purpose: **disconnecting motor power while the Pico stays awake**. Pico GPIO GP15 directly controls its `ON` input with 3.3 V logic, while the external MOSFET carries the servo current. Stopping PWM is not a supply disconnect, and the Pico has no software switch for `VBUS`. A simple USB bench demo can omit power gating after verifying the supply capacity, but then it loses the ability to physically remove servo power between moves. This battery build therefore keeps the regulator's 5 V output branching directly to the gate, with a separate diode-isolated branch to Pico VSYS. [Gate control specification](https://www.pololu.com/product/2810).

### Module settings

- **Master module:** use its physical slide switch as the main on/off control. Leave the `ON` input unused. Put the battery divider downstream of this module alongside the regulator input, so switching off removes voltage from both paths.
- **Servo gate module:** leave its physical slider **OFF** and cover/label it in the enclosure. GP15 drives its `ON` input. A 100 kΩ resistor from `ON` to GND keeps it off while the Pico resets. Turning the physical slider on would bypass the firmware’s ability to remove servo power.

The 2810 is the **non-latching slide-switch LV version**. Do not substitute a similarly shaped Pololu pushbutton/latching board or the higher-minimum-voltage SV version without revising the circuit. Its manufacturer documents a low/disconnected `ON` input as off and an input above approximately 1 V as on. Neither board is an independent safety disconnect. Unplug the battery for servicing. [Pololu 2810 operation](https://www.pololu.com/product/2810).

Leave the S18V20F5 regulator’s **ENABLE** input disconnected. It is pulled toward input voltage and must not be substituted for the servo gate or attached directly to a Pico GPIO. [Regulator documentation](https://www.pololu.com/product/2574).

## Small components and their polarity

| Reference | Component | Connection |
| --- | --- | --- |
| D1 | 1N5819 Schottky | Anode at regulated 5 V, stripe/cathode at Pico VSYS |
| D2 | 1N5819 Schottky | Anode at GND, stripe/cathode at **switched servo 5 V**; clamps negative output transients |
| C1 | Panasonic EEUFR1A471, 470 µF / 10 V | Positive to unswitched regulated 5 V; negative stripe to GND; close to servo gate input |
| R_BLEED | 1 kΩ, ¼ W | Switched servo rail to GND; helps discharge it after shutdown |
| R_EN | 100 kΩ | Servo gate `ON` to GND |
| R_PWM0 / R_PWM1 | 1 kΩ each | Series with each servo signal wire |
| R_TOP | 100 kΩ, 1% | Master-switched raw pack positive → ADC midpoint |
| R_BOTTOM | 47 kΩ, 1% | ADC midpoint → GND |
| C_ADC | 100 nF ceramic | ADC midpoint → GND |

The servo gate has no active output-discharge function; the bleeder does not establish an exact discharge time because each servo’s internal capacitance is unknown. D2 limits negative output excursions; C1 does not make an undersized supply adequate. Confirm clean startup and shutdown with the actual wires and servo load.

Build the passive components and splice points on the **Adafruit 1608 quarter-size Perma-Proto**. It has electrically connected rows and rails; it is not isolated-pad perfboard. Follow its copper connectivity when assigning holes. Carry the motor supply/return between power components using the selected stranded power wire, not an assumed ampacity of the prototype board’s thin rails. Solder and insulate point-to-point connections according to the netlist, then meter every net before installing the Pico. A fully routed per-hole PCB layout is not supplied.

## Harness lengths and routing

Make the harness with the enclosure and chosen boards on the bench. The shopping list buys enough lead length; trim only after confirming the route.

- Battery: keep the holder’s leads long enough to lift out the holder; shorten excess pigtail wire rather than tightly folding it. Keep the inline fuse near battery positive and its cap accessible.
- Power assembly: use short 22-AWG stranded runs, roughly 50–100 mm where the current layout permits; leave enough service slack to remove a board. The holder’s original 24-AWG leads remain the limiting supplied wire segment and must be checked under the actual load.
- Pico logic/VSYS harness: start with roughly 150 mm of the selected stranded hookup wire per connection, then trim after trial assembly. Solder to the Pico’s corresponding edge pads, keeping underside solder inside the checked allowance. These wires do not carry servo motor current.
- Servos: retain the original three-wire connectors. Cut each selected Pololu 2169 extension to retain its mating male end and roughly 100 mm of lead (confirm the required length by dry-fitting first); solder those three leads to the appropriate nets on the power assembly. Insulate the cut wires and provide strain relief. This keeps the original servo detachable without coiling a whole 12-inch extension inside the pod. The full extension and optional three-pin headers can be used on the bench. Route each **signal separately**; a servo Y-cable would send one signal to both motors and is not appropriate for independent control.
- USB: the selected micro-USB **data** cable is for programming/service. Keep its plug insertion space unobstructed; it is removed for the battery installation.
- Use insulated tie anchors/strain relief at enclosure exits. Keep wires out of the moving yoke, out from under lid screw bosses, and away from the Pico antenna zone. Do not trap an unrecessed tie or solder joint between the housing and wall.

Wire-cut lengths and plug bend envelopes are assembly allowances, not dimensional specifications from the servo manufacturer. Confirm them using the revised assembled CAD and the components in hand.

## Before first power

1. With cells removed, check that no positive net is shorted to ground. Confirm the RCY polarity, both diode stripes, capacitor polarity and physical Pico pins.
2. Check the master switch controls both regulator input and the battery-divider supply. With the master off and no USB, the ADC node must not remain energized.
3. Power the regulator without Pico/servos attached and measure its output. Verify the divider voltage remains below 3.3 V across the intended pack range.
4. Attach the Pico with the servo gate physically OFF. Confirm servo output stays off during reset and only GP15 turns it on. USB alone should not power the servo rail.
5. Test one unloaded servo, then the mechanism on a supported fixture. Measure input peaks, startup droop, fuse behavior and heating. The selected 2 A time-delay fuse is a prototype selection; verify it tolerates normal startup and protects the actual wiring before unattended use.
6. Enable battery sensing in configuration only after comparing its reading with a meter. The 4.4 V software threshold inhibits new servo motion; it does not disconnect the entire pack. Recharge externally and add appropriate hardware pack cutoff if unattended discharge protection is required.

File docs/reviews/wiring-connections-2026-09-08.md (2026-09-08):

# Connection and GPIO review — 2026-09-08

Scope: received XL63070 module, switched four-AA holder, ESP32-S2 Mini, one MG90S, and the current solder-prep/breadboard artifacts. This checks intended connectivity and documented interfaces; it is not an electrical test of the user's hardware.

## Result

**The proposed nets are correct. No misplaced power or signal connection was found.** The direct-output-hole version is a sensible simplification: the two devices receive power in parallel, with separate leads meeting at the converter. A three-way splice or power breadboard is unnecessary. The conditional proceed decision and USB procedures in [the combined review](wiring-decision-2026-09-08.md) agree with this review.

Two older instructions need narrower wording: “use one convenient hole” unnecessarily excludes using both duplicate holes in a labeled output group; “disconnect all three S2 harness leads for USB” is a safe isolated-programming procedure, but is not required for a correctly isolated live servo test.

## Verified pin and net mapping

With the S2 component side facing the viewer and USB pointing down, the bottom three pads in the **outermost right row** are VBUS, GND and GPIO16, bottom upward. The neighboring inner row is different: GPIO15, GND and GPIO17. The official diagram was visually checked; do not select a pin solely by approximate position. [WEMOS pinout](https://www.wemos.cc/en/latest/_static/boards/s2_mini_v1.0.0_4_16x9.jpg)

The official schematic connects USB VBUS directly to the VBUS header net and onboard 3.3 V regulator input. Therefore regulated 5 V belongs on VBUS. USB power and an externally driven VBUS are not automatically isolated. Neither 3V3 nor GPIO16 is a 5 V power input. [WEMOS schematic](https://www.wemos.cc/en/latest/_static/files/sch_s2_mini_v1.0.0.pdf)

| Net | Connections |
|---|---|
| Battery positive | Switched holder red → converter VIN |
| Shared ground | Holder black → converter input GND; converter output GND → S2 GND and servo ground |
| Regulated positive | Converter VOUT → S2 VBUS and servo positive |
| Control | S2 GPIO16 → servo signal |

In the received module photo, with the inductor on the left and text upright, VOUT is upper left, output GND upper right, VIN lower left and input GND lower right. Duplicate holes within each labeled group provide alternative physical solder positions on the same intended net. Using one VOUT hole for each load and one output-GND hole for each return is appropriate **after confirming continuity on the unpowered actual board**. VIN and VOUT remain different nets. The two ground groups are intended to be common.

The servo's signal is referenced to shared ground. A connection to GPIO16 does not supply motor power. Keeping common ground during split-supply testing does not join the positive power rails. [Pololu explains the three servo connections](https://www.pololu.com/blog/16/electrical-characteristics-of-servos-and-introduction-to-the-servo-control-interface).

## Breadboard and flying-lead checks

Both repository checks pass:

- `python3 tools/verify_s2_demo.py`: 12 wires, two midpoint rail bridges, shared i38/j38 signal strip and four isolated required nets.
- `python3 tools/verify_solder_prep.py`: seven solder groups, 12 wires, required net separation, rail bridges, photo orientation and GPIO16 profile.

These checks validate the encoded board topology, not a physical breadboard. Check the actual rail breaks unpowered. Within an ordinary five-hole terminal strip, all holes are common; positive and ground must not share one strip. The current headerless S2 flying-lead arrangement is appropriate. Fully populating both adjacent S2 header columns and inserting them into common breadboard strips can short neighboring pins; that is not the arrangement reviewed here.

The direct converter branches make power rails optional. They do not change the required four electrical nets.

## Logic voltage and powered-off behavior

GPIO16 is a 3.3 V-domain signal. Espressif specifies input levels relative to its supply domain, not 5 V tolerance. Do not add a 5 V pull-up or connect servo positive to it. [ESP32-S2 datasheet, DC characteristics](https://documentation.espressif.com/esp32-s2_datasheet_en.html)

A 3.3 V PWM signal is a reasonable initial test: Pololu documents modern receivers using about 3 V pulses and many servos working with 3.3 V microcontrollers. This does **not** establish the input threshold of the user's particular MG90S or clone. Its threshold remains unverified. A level shifter is conditional on a demonstrated interface problem, not a default requirement. [Pololu servo interface details](https://www.pololu.com/blog/17/servo-control-interface-in-detail)

Removing the booster-to-VBUS connection prevents a direct positive-supply connection during USB testing, but does not make GPIO16 electrically isolated. A powered controller sending pulses to an unpowered servo may inject current through input protection. The servo's internal circuit was not identified, so this is a general interface risk rather than a demonstrated fault in this unit. Likewise, a powered servo must not be assumed to back-power the ESP32: its signal is normally an input, but its precise pull-up and powered-off behavior are unknown. [TI describes the general signal-line back-power mechanism](https://www.ti.com/document-viewer/lit/html/SCDA015).

For live USB debugging without added parts:

1. Reconfigure with USB unplugged and cells removed. Physically disconnect and insulate booster VOUT → S2 VBUS; eliminate any equivalent connection through breadboard rails.
2. Establish shared ground. Initially leave the PWM lead disconnected.
3. Power the S2 by USB and the servo by the battery/converter, then connect PWM while both are powered.
4. Disconnect PWM before switching either supply off. Do not command the servo with its supply off.

For isolated programming, disconnecting all three harness leads remains the simplest option. For normal battery use, leave USB unplugged and reconnect the VBUS branch. The battery switch alone does not isolate USB from a still-connected VBUS branch.

`firmware/hardware.py` initializes the signal low and returns it low after stopping/deinitializing PWM. This helps normal operation but does not guarantee all boot, crash or independent-power sequences. Stopping PWM also does not disconnect servo power. A series signal resistor can limit some injection current; it is not a voltage regulator or guaranteed powered-off isolation.

## Findings by category

**Actual connection errors to avoid:** 5 V/raw battery voltage on GPIO or 3V3, VIN-to-VOUT bridges, missing shared ground, joined USB/external positive supplies, and breadboard strips accidentally joining different nets. None was found in the encoded current wiring.

**Conditional bench evidence still needed:** actual terminal continuity and polarity, measured converter output, stable supply at the loads, the servo's 3.3 V signal response, and real breadboard contact topology. No source or drawing substitutes for these checks.

**Optional for this minimal demo:** power breadboard, three-way splices, WAGO connectors, servo power gating, and a signal resistor or level shifter without a demonstrated need. This pin review adds no mandatory shopping list. See the separate power review for converter/load limits and fault protection.

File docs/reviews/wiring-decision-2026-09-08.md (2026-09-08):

# Wiring decision: minimal one-servo demo

Scope: four AA alkaline cells in the switched holder, received XL63070 buck-boost module, ESP32-S2 Mini and one MG90S. This is a review of the proposed circuit and repository artifacts, not a measurement of the assembled hardware.

## Decision

Keep the basic circuit. It is a reasonable candidate for a short supervised bench demonstration once the output voltage and behavior under load are checked. It has not been proven to supply the actual servo's peak current, survive a short circuit, or tolerate a stalled mechanism.

No redesign or mandatory shopping list follows from the schematic alone. Correct polarity, insulation, a measured 5 V output, appropriate USB isolation, and a free-moving servo are prerequisites. Additional monitoring and switching circuitry are optional for this trial; unreliable power under load would require a concrete fix before continuing.

## Battery-only demo: recommended normal arrangement

```text
4 AA holder red (already switched) ─────────── XL63070 VIN
4 AA holder black ────────────────────────── XL63070 input GND

XL63070 VOUT hole A ──────────────────────── S2 VBUS / 5V
XL63070 VOUT hole B ──────────────────────── Servo red (+)
XL63070 output GND hole A ────────────────── S2 GND
XL63070 output GND hole B ────────────────── Servo brown/black (−)
S2 GPIO16 ───────────────────────────────── Servo signal

USB UNPLUGGED
```

Duplicate output holes within each labeled group let the PCB act as the junction: a three-way wire splice and power breadboard are not necessary. Confirm same-group continuity with power disconnected before using them. VIN and VOUT are different nodes; never bridge them. Both devices need ground, and the converter's input/output grounds are common. Keep the servo supply and return leads separate from the S2 leads until they meet at the converter.

The received-photo orientation is VOUT top left, GND top right, VIN bottom left, GND bottom right. S2 component side up with USB down: the bottom three pads of the outermost right row are VBUS, GND, GPIO16 from bottom upward. Match actual labels, especially if changing boards. Never put 5 V on 3V3 or GPIO16.

## USB modes: distinguish programming from live servo testing

The [official S2 Mini schematic](https://www.wemos.cc/en/latest/_static/files/sch_s2_mini_v1.0.0.pdf) ties USB VBUS directly to the board's VBUS/5V pad. It does not isolate a connected external 5 V source from USB power.

| Mode | USB | Booster → S2 VBUS | Signal and ground |
|---|---|---|---|
| Battery demonstration | Unplugged | Connected | Connected |
| Programming with hardware isolated | Connected | Disconnected | All three S2 harness leads unplugged |
| Live USB debugging with battery-powered servo | Connected | **Physically disconnected and insulated** | Common ground stays; signal only while both devices are powered |

For live testing:

```text
Mac USB ────────────────────────── S2 power
Battery → booster VOUT ─────────── Servo power ONLY
Booster GND ──────────────────┬─── Servo GND
                              └─── S2 GND
S2 GPIO16 ───────────────────────── Servo signal (removable)

NO booster VOUT connection to S2 VBUS, directly or through a breadboard rail.
```

Change the power wiring with USB unplugged and cells removed. For the split-supply live-test mode, establish common ground, keep the signal disconnected until both devices are powered, then connect only that signal lead. Disconnect the signal before shutting down either supply. Do not issue commands while the servo supply is off. This avoids relying on undocumented powered-off behavior of the servo input. It is a precaution for this unknown module, not a claim that a specific internal protection circuit has been identified. [TI explains the general signal-line back-power mechanism](https://www.ti.com/document-viewer/lit/html/SCDA015).

Keeping common ground does not join the two positive supplies. Turning off the battery switch alone does not remove the direct USB/booster connection if the VBUS wire is still installed. Stopping PWM likewise does not disconnect servo power.

## Minimum bench evidence before calling it a working demo

1. **Unpowered wiring check:** cells removed and USB unplugged. Inspect for reversed leads, loose strands and solder bridges. Check duplicate-hole continuity and any breadboard rail splits. Do not use continuity mode on powered wiring; a brief capacitor-charging response is different from a sustained hard short.
2. **Converter alone:** S2 and servo disconnected. Black meter lead in COM, red in V/Ω, DC voltage mode. Measure approximately 5.0 V from VOUT to GND. The board's printed 5V label or purchased variant does not replace this measurement. Do not connect a meter set to current across a supply.
3. **S2 alone on battery:** verify it boots, joins Wi-Fi and serves the page with USB absent. Switch off before adding the servo.
4. **Unloaded servo:** horn clear of the switch mechanism, conservative movements. Check voltage at the loads, not just the converter. Stop for resets, repeated jitter, sag, a stalled motor or heating at cells, wires, contacts or converter. A multimeter can miss brief dips.
5. **Short gentle switch test:** only after the unloaded test succeeds. Avoid mechanical binding. The software returns to neutral and stops pulses, but it cannot sense a stall or certify that torque has been released.

Fresh AA cells are suitable for this trial, but not a guarantee of peak current. A seller's “2 A maximum” is not a measurement of continuous output at low battery voltage. Converter, holder, wiring and contacts must work together under the real load. The 3.3 V control signal is a reasonable initial choice, but the supplied servo's exact input threshold is unverified; no movement does not by itself prove a power fault. [Pololu's servo interface explanation](https://www.pololu.com/blog/16/electrical-characteristics-of-servos-and-introduction-to-the-servo-control-interface) distinguishes power, ground and control and explains load-dependent current.

## What we are not adding by default

- A servo power gate, battery ADC, WAGO blocks or a separate holder switch: unnecessary for this demo's requested behavior.
- A signal resistor: not a voltage regulator, power-source selector or substitute for correct power sequencing.
- A bulk capacitor: consider it for demonstrated transient trouble; it cannot repair inadequate sustained current or a bad connection.
- A level shifter: add only if the actual servo fails a correctly powered 3.3 V signal test and the required interface is established.

A fuse is useful fault protection, not a logic requirement. The minimal unfused prototype does **not** protect its complete wiring against shorts: supervision does not make it short-proof. Keep joints insulated, assemble unpowered, and remove cells when finished. An unattended installation or evidence of excessive fault/load current needs a protection review before use.

## Reviews and checks

- [Power critic](wiring-power-2026-09-08.md)
- [Connection and GPIO critic](wiring-connections-2026-09-08.md)
- [Practical demo critic](wiring-demo-2026-09-08.md)

Both existing drawing net checkers pass. Source inspection of `firmware/hardware.py` confirms GPIO is set low at initialization and after PWM deinitialization. `firmware/control.py` bounds normal commands with a timeout and runs cleanup in `finally`. These are useful behaviors, not a current limiter or a guarantee about every boot, crash or separately switched power condition. No firmware was changed, enabled or flashed during this review.

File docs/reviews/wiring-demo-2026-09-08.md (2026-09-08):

# Critical review: minimum supervised wiring demo

Reviewed 2026-09-08. Scope: four AA alkaline cells in the switched holder → received XL63070 module → measured approximately 5 V → ESP32-S2 Mini VBUS and one MG90S in parallel; common ground; GPIO16 signal. No physical measurements were made in this review. No CAD, firmware, private files or hardware were changed.

**Conditional go for staged, attended bench testing. No unconditional electrical-capacity approval.** The simple topology is reasonable. Secure connections, output-voltage verification, USB isolation and conservative servo motion are the minimum. A gate, signal resistor, extra capacitor or battery monitor is not automatically necessary for the first demonstration. Unknown converter/holder/contact/servo ratings prevent approving continuous load, a jammed mechanism or unattended use.

## Main findings

| Failure mode | Consequence | Minimum action for this demo |
|---|---|---|
| Wrong converter selection, reversed connector or mistaken S2 pad | Supply applied to the wrong node can damage parts immediately. | Verify actual labels and polarity with power removed; measure converter output before connecting either load. VBUS is the supply input here; 3V3 and GPIO16 are not 5 V supply pins. |
| USB and converter both connected to S2 VBUS | USB and converter outputs become tied together. Battery OFF does not isolate the USB supply from the converter output or servo rail. | Physically disconnect and insulate the converter-to-S2-VBUS lead before USB use. Keep this disconnect accessible. |
| Loose strands, oversized/tinned blobs in breadboard contacts, twisted bare splices | Intermittent supply, adjacent-pad shorts, local heating or a pulled-off PCB pad. | Use secure insulated solder/crimp joints and correct breadboard pins or solid wire ends. Provide strain relief. Do not use loose twists as finished joints. |
| Servo start/reversal/load spike through a resistive contact chain | Servo jitter, controller resets or misleading command failures. | Prefer short separate supply/return branches from converter output to each load. Watch voltage at the load connectors, not just at the converter. Stop on resets or repeatable jitter. |
| Servo reaches a mechanical stop or pushes continuously after the switch flips | High current and heating; mount damage or repeated brownout/reboot motion. | First test with no switch load. Start near neutral with small moves. Do not deliberately stall it or leave it buzzing against the switch. |
| USB powers the ESP while the servo is switched off, but PWM remains active | Possible current injection through the servo input; exact behavior of this servo is undocumented. | Stop PWM and hold the signal low/high-impedance before servo power-off, or disconnect the signal lead. If software behavior is unknown, use the physical signal disconnect. |
| Meter lead left in a current socket during voltage measurement | Meter can short the supply. | Black lead in COM, red in V/Ω, DC voltage mode. Current measurement is not required for the first spin. |

The [WEMOS S2 Mini schematic](https://www.wemos.cc/en/latest/_static/files/sch_s2_mini_v1.0.0.pdf) directly connects the USB VBUS net to the board's VBUS header and regulator input. That supports the power-source isolation finding; it does not establish the rating of the user's clone, connector or soldered harness.

[BusBoard's breadboard guidance](https://www.busboard.com/faq) specifies suitable solid-core wire for its products, and its [BB830 specifications](https://busboard.com/BB830T) describe a particular contact system. Those ratings must not be transferred to an unidentified breadboard. Factory male jumper ends or correctly sized solid-wire ends are preferable to forcing a bundle of solder-tinned strands into an unknown spring contact. Poor contact can fail before the converter reaches its advertised limit.

[Pololu's servo electrical overview](https://www.pololu.com/blog/16/electrical-characteristics-of-servos-and-introduction-to-the-servo-control-interface) distinguishes idle and stall demand, while its [motor/power-supply guidance](https://www.pololu.com/docs/0J73/4.1) explains why starting and stalled motors demand more current than a freely running motor. This is general guidance, not an MG90S current measurement. Do not assign the user's servo a guessed stall-current rating or run it into a stop to discover one.

The powered-off signal warning is a **precaution based on a known IC failure mechanism, not proof of this servo's internal circuit**. [TI documents back-powering through input protection structures](https://www.ti.com/lit/ab/scda015c/scda015c.pdf?ts=1781771181252). The MG90S signal-input circuit and powered-off tolerance are not established here. Removing only the converter-to-VBUS wire solves the USB supply tie, but does not by itself solve a powered signal into an unpowered servo.

## Simplest practical distribution

The two duplicate VOUT holes may carry separate leads to S2 VBUS and servo positive; the two duplicate output-GND holes may carry separate returns from S2 GND and servo ground, **after confirming those duplicate holes share their labeled net with power removed**. This preserves the same parallel topology and can eliminate the breadboard power rails entirely. It does not double the module's current rating or provide independent regulated outputs.

Use one secure termination per chosen hole, with insulation and strain relief that do not load the PCB pad. Keep the signal lead distinct from power. If using the existing breadboard instead, verify every used rail segment and bridge any required split with power removed. Avoid routing servo supply current through the controller board or through a long chain of jumper contacts. These are practical reductions in connection resistance and failure points, not a certification of the remaining wiring.

## Power modes and sequencing

| Mode | Converter → S2 VBUS lead | USB | Ground/signal |
|---|---|---|---|
| Battery-only demo | Connected | Unplugged | Common ground and GPIO16 connected. |
| USB programming, servo power off | Disconnected and insulated | Connected | Ground may remain; disconnect the servo signal unless its inactive state is verified. |
| Live USB debugging while battery powers the servo | Disconnected and insulated | Connected | Common ground **must remain**; signal may remain while the servo is powered. Disable/disconnect signal before switching servo power off. |

Set up or change the power wiring with both sources disconnected. A live-debug session can retain ground and signal; removing all three harness leads is the simpler isolation procedure for programming without servo operation, not an electrical requirement for every debug session. Do not replace the missing positive lead with a jumper elsewhere on the breadboard. If there is any uncertainty about isolation, use the battery-only demo or disconnect the whole harness before USB programming.

## Minimum go/no-go bring-up

1. **Unpowered inspection.** Remove cells and unplug USB. Inspect the seven terminal groups, plug polarity, free strands and solder bridges. Confirm intended ground/duplicate-pad continuity and any breadboard joins. A transient continuity beep can result from capacitors charging; a sustained near-short between positive and ground needs investigation. Continuity/resistance tests are unpowered only. Place the assembly on a stable insulating surface with the switch accessible.
2. **Converter only.** Leave S2 and servo supply leads detached. With meter leads in COM and V/Ω and DC-voltage mode selected, connect probes so they cannot slip across neighboring pads. Install correctly oriented cells, switch on, record VIN-to-input-GND and VOUT-to-output-GND. **Go only if output is approximately 5.0 V and polarity is correct.** A raw-pack-like value or another selection is a no-go. The purchase option and apparent link position are not measurements. Switch off before connecting a load.
3. **S2 alone, battery only.** Connect its VBUS and ground with USB absent. Confirm the page remains reachable during Wi-Fi activity. Record voltage at the S2's VBUS/GND pads. Reboots, unstable connection accompanied by resets, or a large drop from converter VOUT are a no-go pending diagnosis.
4. **Add the servo, unloaded.** Switch off first and connect the servo, with its output free of the switch mechanism. Start with a few small movements near the intended neutral position. Record voltage at the servo supply connector and watch the S2 for resets. Stop for repeated jitter, uncommanded motion, sustained straining noise, warm leads/contacts/cells, rapidly increasing converter temperature or odor. Do not touch exposed energized pads to assess temperature; switch off before handling.
5. **Gentle switch trial only after the unloaded test passes.** Use a few short actuations with conservative endpoints. The mechanism must finish without the servo remaining forced against a hard stop. Keep hands clear of moving parts and power off promptly if motion binds. This establishes only that the tested motion worked under the tested battery/load conditions.

Do not treat a successful web response as evidence that the servo moved, or one successful flip as evidence of reliable current capacity. After any short, reset or overheating event, disconnect power and find the cause before repeating the test.

[Fluke's multimeter guidance](https://media.fluke.com/ade6b718-4577-4b57-903b-b10600664c67_original%20file.pdf) explains why a voltage test with the lead in the current jack can create a short. Use voltage measurements first; any later current measurement requires the correct fused range and a series connection, with power off while rearranging leads. Never put an ammeter directly across the battery or output.

## Measurements to record, and what they establish

| Measurement | First trial? | Purpose / limit |
|---|---|---|
| Converter VIN and unloaded VOUT, including polarity | Required | Finds reversed input/output or wrong output setting. Does not prove load capacity. |
| S2 VBUS-to-GND during Wi-Fi operation | Required | Checks the controller's actual supply connection. Slow display may miss transients. |
| Servo connector supply during small motion, then gentle switch load | Required | Checks voltage delivered through the complete power path. Record reset/jitter/strain observations as well. |
| Converter VOUT versus load-end voltage during comparable motion | If the first motion fails or sags | A substantial difference points to lead/contact loss; sag at both ends points upstream. Sequential meter readings are only approximate for changing loads. |
| Minimum/maximum voltage, with meter model and capture speed | If available | Useful screening, but not a blanket transient pass. |
| Oscilloscope capture at servo supply and S2 VBUS/3V3 | Needed to resolve unexplained resets/jitter before claiming reliability | Separates brief dips/noise from slow average voltage. Not a required purchase before the first supervised motion. |
| Actual working-current peaks, temperature rise over intended duty cycle, lower-battery behavior | Before continuous/unattended approval | Establishes evidence for supply, protection and runtime choices. Do not obtain these by deliberately jamming the servo. |

A basic DMM showing 5.0 V can miss short disturbances. [Fluke's fast/peak min-max explanation](https://www.fluke.com/en-au/learn/blog/digital-multimeters/under-utilized-functions-how-to-use-fast-peak-min-max-on-your-dmm) makes clear that fast capture is a particular instrument feature, not something every meter's normal display or MIN/MAX mode guarantees. Stable readings and successful small movements are screening evidence, not proof of transient headroom.

## Essential now versus optional changes

- **Essential now:** correct measured voltage and polarity; secure insulated connections; clear USB power-source separation; common ground; inactive/disconnected signal when the servo is off; staged unloaded testing; immediate stop on electrical or mechanical trouble.
- **Not inherently needed for this first functional trial:** servo power gate, battery ADC, extra switch, WAGO connectors or a breadboard. Direct branch wiring can be simpler than rail distribution.
- **Signal resistor:** not a voltage regulator or automatic logic-level converter. It may limit fault/injection current or help signal integrity, but a random value does not establish powered-off safety or compatibility. Keep the signal at the ESP32's logic level; resolve actual input compatibility if it fails despite a sound supply.
- **Extra capacitor:** a possible response to measured transient trouble. It cannot repair poor joints, undersized sustained supply capacity or a jammed mechanism. A capacitor value and location should follow the observed problem and regulator requirements rather than being treated as a universal cure.
- **Fuse/current limiting:** valuable fault-energy protection, not required to make the logical circuit function. An unfused AA prototype is not protected merely because the voltage is low or someone is watching. The limited demo relies on careful disconnected-power assembly and immediate intervention; unknown wire/holder/servo current limits prevent selecting a defensible fuse rating here. Protection must be resolved before an unattended installation or a claim of fault tolerance.

No added component is a substitute for correcting a wiring fault or a stalled mechanism. The minimum circuit remains conditional on the physical checks above.

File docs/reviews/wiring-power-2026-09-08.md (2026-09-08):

# Power-path review — 2026-09-08

Scope: received XL63070 module (Teyleten Robot Amazon B0GCW44FDL), switched four-AA alkaline holder, LOLIN-reference ESP32-S2 Mini, one MG90S-type servo. Header pins versus soldered wires do not change the electrical nets. No hardware, firmware, or private configuration was accessed.

**Verdict:** the direct output forks are electrically sensible for a supervised trial. The split-supply USB-debug variant is also valid **when the converter-to-S2 VBUS path is physically disconnected**, with common ground retained. Current capacity and servo transients remain untested. Treat signal connections across independently switched supplies as a separate sequencing issue.

## Must be correct before power is applied

1. **Use the right supply pads.** Battery red goes to converter VIN; battery black to input GND. Measured 5 V VOUT goes to S2 **5V/VBUS**, never 3V3 or GPIO16. Servo power gets a separate VOUT branch and separate output-GND return. The S2's VBUS supplies its onboard 3.3 V regulator; it is not the chip's 3.3 V rail. [Official WEMOS schematic](https://www.wemos.cc/en/latest/_static/files/sch_s2_mini_v1.0.0.pdf)

2. **Identify the received converter by its labels.** In `IMG_3222.JPG`, VOUT is upper left, GND upper right, VIN lower left, GND lower right. The two holes in each large terminal pad are duplicate connection points. Using both VOUT holes to feed two branches, and both output-GND holes for returns, does not create two independently regulated outputs or double the available current. Verify duplicate-pad continuity with all power removed if the actual soldering/labels are unclear.

3. **Verify output selection with a meter.** The [exact seller listing](https://www.amazon.com/dp/B0GCW44FDL) describes 3.3/5/9 V links and allows one selection at a time. Leave configuration pads unchanged during wire preparation; measure VOUT-to-GND with both S2 and servo disconnected. Target approximately 5.0 V. A listing option, “5V” silk label, or apparent bridge is not proof. Do not use a resistor to drop raw four-AA voltage to 5 V.

4. **Never join USB 5 V to converter VOUT through the S2.** VBUS on the [LOLIN reference schematic](https://www.wemos.cc/en/latest/_static/files/sch_s2_mini_v1.0.0.pdf) is directly tied to USB VBUS. Turning the holder switch off does not disconnect the converter's output from the S2. There is no established reverse-blocking guarantee for this received converter. Do not rely on a presumed diode, USB-port protection, or unverified chip identity to make parallel supplies acceptable.

5. **Insulate the disconnected positive lead in USB-debug mode.** Remove the booster-to-S2 VBUS wire physically, not merely its battery supply. Verify that no breadboard positive rail or second lead reconnects those nets. Keep GND common; removing ground while leaving a control signal is not a power-isolation method. The servo must draw its motor current through its own return to the converter, not through the S2's small ground lead.

6. **Avoid driving an unpowered device through GPIO16.** The servo input circuit is unknown. Independently switched supplies can leave a powered signal connected to an unpowered receiver. General CMOS I/O can conduct into an unpowered supply unless specifically designed for power-off isolation; this is a possible path, not a claim that this servo contains a particular protection diode. [TI discussion of partial-power-down I/O](https://www.ti.com/lit/an/scea026/scea026.pdf) ESP32-S2 GPIO levels also must remain within its supply-related limits; 5 V is not an acceptable signal. [ESP32-S2 datasheet, DC characteristics](https://www.espressif.com/sites/default/files/documentation/esp32-s2_datasheet_en.pdf)

For a simple USB-debug procedure, leave the signal disconnected until both devices are powered and the ESP32 output is in a known inactive state; connect it only for the test. Disconnect the signal before shutting down either supply. Ground can remain connected. An explicitly verified inactive-low sequence may replace physical signal disconnection for controlled shutdown, but unexpected brownouts remain outside that guarantee. The earlier instruction to remove **all three** S2 leads remains a valid fully disconnected programming procedure; it is not the only possible arrangement.

## The two valid power arrangements

```text
BATTERY DEMO — USB absent

4AA + switch → converter VIN
converter VOUT ──┬── S2 VBUS
                 └── servo +
converter GND ───┬── S2 GND
                 └── servo GND
S2 GPIO16 ────────── servo signal

USB DEBUG — converter-to-S2 VBUS lead removed and insulated

USB ──────────────── S2 USB connector / VBUS
4AA + switch → converter VIN
converter VOUT ───── servo +        [NO connection to S2 VBUS]
converter GND ───┬── servo GND
                 └── S2 GND         [common reference retained]
S2 GPIO16 ────────── servo signal    [connect only while both powered]
```

## Bench-test unknowns — do not turn these into guarantees

- **Total output capacity:** the module listing advertises 2 A maximum, not proven continuous 5 V output under every input/thermal condition. Both branch currents count against the same total. No TI chip performance or reverse-current specification is assumed to apply to this assembled XL63070-labeled unit.
- **Low-input demand:** for illustration at 85% efficiency, 5 V × 1 A requires about 0.98 A from a 6 V pack, but about 1.47 A from a 4 V pack. These are calculated examples, not measured servo current. Cells, holder switch, contacts, solder joints, and wires may be the limit. Alkaline voltage and usable capacity vary with loading; use fresh matched cells for the first demo. [Energizer alkaline application manual](https://data.energizer.com/pdfs/alkaline_appman.pdf)
- **Actual servo peak current and supply transients:** this clone's stall/starting current is unmeasured. Servo current can pulse strongly when starting, correcting position, or changing load; a vendor's measurements of other servos demonstrate the mechanism, not this unit's numeric demand. [Pololu servo measurements](https://www.pololu.com/blog/17/servo-control-interface-in-detail)
- **No-load 5 V is insufficient validation:** check S2-only operation, then short unloaded servo motion, then modest mechanical load. Observe both converter output and voltage at the load connectors. Stop on resets, jitter, sag, or heating. A multimeter may miss short droops or overshoot. Do not deliberately stall the servo. USB-debug isolates the ESP32's positive supply but does not prove battery-demo stability.
- **Signal tolerance:** the received servo's documented 3.3 V threshold and power-off behavior are unavailable. Stable power plus absent/unreliable motion requires signal investigation; it does not justify putting 5 V on an ESP32 GPIO.

## Optional improvements, not prerequisites for initial function

Extra bulk capacitance, a signal series resistor, a fault fuse, or a power-selection/isolating buffer circuit may improve a later design. They are not substitutes for correct pad selection, physical supply separation, and voltage verification. A capacitor cannot compensate for insufficient steady current. A series resistor is not a level shifter or assured isolation. Power gating, battery ADC, WAGO connectors, and another switch are unnecessary for this minimal supervised test.

The unfused assembly is not certified short-circuit protected. Remove cells and USB before soldering or changing power connections, retain insulation/strain relief, and do not infer unattended-operation approval from a successful short test.

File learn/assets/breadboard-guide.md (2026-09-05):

# Breadboard bench build

Use the [interactive Breadboard tab](../learn/index.html#breadboard), [full layout](../hardware/wiring/breadboard/layout.svg) and [hole checklist CSV](../hardware/wiring/breadboard/placements.csv). This is a temporary bench version of the same circuit. The final enclosure still uses the headerless Pico and soldered wiring; this layout does not claim that the breadboard fits the STLs.

## What to add

| Item | Quantity | Purpose |
| --- | ---: | --- |
| [Adafruit 239 full-size 830-point breadboard](https://www.adafruit.com/product/239), or a matching 63-row board | 1 | Two five-hole strips per numbered row, columns a–j |
| [Adafruit 1957, 20 male/male 150 mm jumpers](https://www.adafruit.com/product/1957) | 1 pack | Eight complete jumpers plus six cut-to-one-male-end leads for two servos; seven plus five for one servo |
| Existing Pico W with two straight 20-pin male headers | 1 | Headerless board is for the final assembly; no extra Pico required for the bench if yours matches |
| Components, 22 AWG power wire, heat-shrink and servo extension(s) from the [BOM](../BOM.md) | As listed | Same electrical circuit; Perma-Proto is not needed for the breadboard stage |

The 150 mm jumpers are 28 AWG. Use them for Pico supply and logic branches, not the motor-current path. For L1–L6, retain one male end for the breadboard and solder/insulate the other end into its named external connection. Do not push frayed stranded wire directly into the holes. Keep the existing thicker power harness between battery, regulator, gate and servo(s).

The regulator and Pololu 2810 modules support 0.1-inch headers, but this layout deliberately keeps their motor power connections beside the breadboard on direct wiring. This is a reliability choice for this prototype, not a claim that those modules cannot fit a breadboard. [Regulator](https://www.pololu.com/product/2574), [switch module](https://www.pololu.com/product/2810).

## Board orientation and connected holes

Place the breadboard with its numbered rows increasing downward, a–e on the left and f–j on the right. Put the Pico USB socket at the **top**. Its first left pin goes into **c3**, first right pin into **h3**; the bottom header pins are **c22** and **h22**. Do not shift it down one row and keep using this table.

The Pico header rows are 17.78 mm apart. Across a standard board, c→d→e (5.08 mm), the e/f trench (7.62 mm), and f→g→h (5.08 mm) total 17.78 mm. Columns a/b and i/j remain exposed. [Pico W physical drawing](https://datasheets.raspberrypi.com/picow/pico-w-product-brief.pdf), [official pinout](https://datasheets.raspberrypi.com/picow/PicoW-A4-Pinout.pdf).

Each numbered row has two separate metal strips: a–e and f–j. Thus b35 connects to the diode lead in a35; j4 connects to Pico VSYS in h4. Adjacent rows are separate. **All side power rails are unused**, avoiding assumptions about split rails. Confirm strip continuity with your own board before placing parts. [Adafruit breadboard guide](https://learn.adafruit.com/breadboards-for-beginners/breadboard-tips-and-tricks).

| Pico function | Physical pin | Header hole | Accessible jumper hole |
| --- | ---: | --- | --- |
| VSYS | 39 | h4 | j4 |
| GND | 38 | h5 | j5 |
| GP15 / gate enable | 20 | c22 | b22 |
| GP16 / first signal | 21 | h22 | j22 |
| GP17 / second signal | 22 | h21 | j21 |
| GP26 / ADC | 31 | h12 | j12 |

VBUS pin 40 at h3 and 3V3 OUT pin 36 at h7 have no external wires. The board's USB socket remains available for programming.

## Place parts with all power disconnected

Resistors have no polarity. For axial parts spanning five rows, form the leads gently to the hole spacing while supporting the lead near the body. Do not force the body down or strain the ceramic capacitor. The resistor bands show nominal five-band 1% parts; confirm the resistance/value of the purchased part with a meter.

| Part | First hole | Second hole | Important detail |
| --- | --- | --- | --- |
| D1, 1N5819 | a30 anode | a35 cathode | Silver stripe toward row 35 |
| R_TOP, 100 kΩ 1% | a40 | a45 | Battery divider upper resistor |
| R_BOTTOM, 47 kΩ 1% | b45 | b50 | Battery divider lower resistor |
| C_ADC, 100 nF ceramic | e45 | e46 | Non-polar; adjacent rows, **not two holes in one row** |
| R_EN, 100 kΩ | a55 | a60 | Gate-enable pulldown |
| R_PWM0, 1 kΩ | f30 | f35 | First servo signal series resistor |
| R_PWM1, 1 kΩ | f40 | f45 | Second servo only |

| Jumper | From | To | Function |
| --- | --- | --- | --- |
| J1 | b35 | j4 | D1 cathode to VSYS |
| J2 | c50 | j5 | Ground to Pico |
| J3 | b22 | b55 | GP15 to gate-enable strip |
| J4 | j22 | j30 | GP16 to R_PWM0 input |
| J5 | j21 | j40 | GP17 to R_PWM1 input; second servo only |
| J6 | d45 | j12 | ADC divider junction to GP26 |
| J7 | d46 | d50 | Capacitor return to ground strip |
| J8 | b60 | e50 | Enable-pulldown return to ground strip |

The five sockets a50–e50 are all used, once each. A wire laid over other holes does not connect to them; only the two inserted ends count. Use the hole table rather than interpreting a cable crossing as a junction.

## Connect the power harness beside the board

The right-hand diagram cards label **electrical destinations**, not the positions of the module pads. Use the actual modules' printed VIN/VOUT/GND/ON labels and the [continuous circuit map](../hardware/wiring/connection-map.svg).

Build and insulate the battery → fuse → RCY → master → regulator → gate → servo power path according to the [wiring guide](wiring.md). The RCY disconnect breaks both battery leads. Connect all grounds on this power assembly. Add **C1** positive to regulator 5 V, negative stripe to ground near gate VIN; **D2** stripe to switched servo 5 V, anode to ground; and **R_BLEED** between switched servo 5 V and ground. Neither D2 nor the bulk capacitor belongs on the ADC strip. Keep master ON and regulator ENABLE unused; the servo gate's physical slider stays OFF.

| Lead | Breadboard end | External destination |
| --- | --- | --- |
| L1 | b30 | Regulated 5 V junction P5V (REG VOUT, gate VIN, C1 positive) |
| L2 | a50 | Common ground junction PGND |
| L3 | b40 | PACK_SW junction: master VOUT / regulator VIN, before regulation |
| L4 | c55 | Servo gate ON input |
| L5 | j35 | Servo 0 signal conductor only |
| L6 | j45 | Servo 1 signal conductor only; second servo only |

P5V, PACK and PGND are names for insulated wire junctions, not additional boards to purchase. Retain the servo's original mating plug using the selected extension: its power and ground wires go to the external harness, and its signal wire joins L5 or L6. Confirm the actual wire order; do not rely on colors alone. The motor current must have its direct positive and return path, independent of the breadboard.

## First-power checks

1. With USB and batteries disconnected, check every part and jumper against the tables. Check no positive net is shorted to GND; check D1, D2 and C1 polarity. Confirm your breadboard copper strips match the diagram.
2. **Lift the Pico out of the breadboard**, leaving jumpers in place. Disconnect both servos. Connect the external harness including L1, L2 and L3; this lets you test without applying unknown voltages to Pico pins.
3. Insert the four matched NiMH cells, turn the master on, and use the meter in **DC voltage mode**, black probe in the free hole c60 (GND). Measure free hole c30: nominal regulated **5 V**. Measure free hole c35: the diode-fed Pico supply, below or very close to 5 V with no load; it must never exceed the Pico's 5.5 V VSYS maximum. A diode drop is load-dependent, so do not require a fixed 4.7 V reading.
4. Measure free hole c45: approximately pack voltage × 47/147; e.g. **1.53 V at 4.8 V pack**, or **2.05 V at 6.4 V pack**. It must be below 3.3 V with margin. Compare L3's measured pack voltage and the actual resistor values. Do not insert the Pico if readings disagree.
5. Turn the master off, unplug the battery connector, verify the rails have fallen, then reinstall the Pico at c3/h3. Connect USB for firmware/configuration as needed. Verify the servo gate slider is OFF and its output is off at startup.
6. With power removed again, attach **one unloaded servo**. Power up and use the project's calibrated, bounded motion procedure. The second servo stays unplugged until the first works. Check supply droop and connections before trying the mechanism. Firmware is fail-closed until calibrated; this diagram does not authorize an automatic full-angle sweep.

Do not put a meter in current mode across the battery terminals. No electrical or physical assembly has been tested by generating this diagram; these are instructions and checked design geometry.

## Rebuild and electrical validation

`hardware/wiring/breadboard/layout.json` is the canonical hole plan. The generator creates the SVG and CSV. The independent validator joins actual five-hole strips and declared wires, then checks them against all harness terminals. It does not electrically join the two ends of resistors or diodes when comparing nets. It also checks all 40 Pico header positions, unused-pin isolation and hole occupancy.

```sh
python3 tools/render_breadboard.py
python3 tools/verify_breadboard.py
python3 tools/build_learning.py
python3 -m unittest discover -s tests -p 'test_breadboard.py' -v
```

Both one- and two-servo profiles pass the design checks. This does not measure breadboard contact quality, wire resistance, lead clearances, radio performance or real startup current.

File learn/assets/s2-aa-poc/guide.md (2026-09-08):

# ESP32-S2 Mini / four-AA / one-servo POC

This is the current **bench wiring reference**. It supersedes the Pico-specific POC wiring for this build; the old diagrams remain historical references. The [S2 firmware profile](https://github.com/eoinest/auto-switch/blob/main/docs/s2-firmware.md) now runs on the connected board; Wi-Fi and the ESP32-hosted two-button website were tested over USB power. The servo and battery circuit remain untested.

For the actual received XL63070 board and headerless S2, start with the **[solder-prep map](https://github.com/eoinest/auto-switch/blob/main/hardware/wiring/solder-prep/solder-prep.png)** and [pad checklist](https://github.com/eoinest/auto-switch/blob/main/docs/solder-prep.md). See the [latest three-critic electrical review](https://github.com/eoinest/auto-switch/blob/main/docs/reviews/wiring-decision-2026-09-08.md).

Open [the interactive illustrated map](https://github.com/eoinest/auto-switch/blob/main/learn/s2-aa-poc.html), [PNG](https://github.com/eoinest/auto-switch/blob/main/hardware/wiring/s2-aa-poc/breadboard.png), [SVG](https://github.com/eoinest/auto-switch/blob/main/hardware/wiring/s2-aa-poc/breadboard.svg), or [wire checklist](https://github.com/eoinest/auto-switch/blob/main/hardware/wiring/s2-aa-poc/connections.csv). Every wire is shown in one view. Illustrations reconstruct the component appearance but are not dimension drawings.

## Selected components

| Part | Quantity | Reference / status |
|---|---:|---|
| ESP32-S2 Mini | 1 | User-owned. Drawing uses [LOLIN S2 Mini V1.0.0](https://www.wemos.cc/en/latest/s2/s2_mini.html), 34.3 × 25.4 mm; the user confirmed a headerless board; exact clone and soldered harness still require fit checks. |
| DAIERTEK switched four-AA holder | 1 | User ordered [Amazon B09N1GDWQ9](https://www.amazon.com/dp/B09N1GDWQ9), nominal 68.7 × 64.2 × 22.5 mm. Integrated switch replaces the separate rocker. |
| Amazon Basics AA alkaline cells, 1.5 V | 4 | User ordered. In series: 6 V nominal; raw battery never feeds the ESP32 directly. Do not recharge these cells. |
| Teyleten Robot 5 V buck-boost module | 1 | Selected [Amazon B0GCW44FDL](https://www.amazon.com/dp/B0GCW44FDL). Title says TPS63070; product PCB photo says XL63070. Published board dimensions and authentic chip identity not established. Selection pads, not an adjustment screw. |
| MG90S 180° servo | 1 | User-owned. Verify plug wire colors and orientation on actual servo. |
| Solderless breadboard | 1 | User-owned; exact model unknown. Illustration uses generic 830-point topology with 63 five-hole rows and split 50-hole rails. Adapt to actual board, verified unpowered with continuity mode. |
| Direct-solder leads with male breadboard ends | 3 | Headerless S2 to breadboard: VBUS, GND, GPIO16. Insulate joints and add strain relief; no female header sockets are needed on this board. |
| Male-to-male jumpers | 5 | Three into the servo female plug and two rail midpoint bridges. Use shortest practical power leads. |
| Two converter-output leads with male breadboard tips | 2 | Solder stripped ends to converter output; use clean factory pins or 22 AWG solid ends at breadboard. |
| Solder, suitable insulation and strain relief | As needed | User-owned tools/materials. No soldering directly to the breadboard. |

No external servo gate, signal resistor, extra capacitor, battery ADC, WAGO, separate rocker, or isolation diode is installed in this minimal bench map. The converter includes its own capacitors. Short-circuit protection and load capacity of the complete battery/holder/breadboard assembly are not certified by this drawing. Keep this as a supervised bench test; disconnect cells before modifying wiring. A permanent unattended build needs a separate protection and power-distribution review.

## Wiring and board orientation

Use the [WEMOS official pinout](https://www.wemos.cc/en/latest/_static/boards/s2_mini_v1.0.0_4_16x9.jpg): top/component side facing you, USB connector pointing **down**. On the **outermost right row of pads**, the bottom three pins are, from bottom upward: **VBUS (often labelled 5V), GND, GPIO16**. Inner pins are different. The S2 Mini has no Pico-style VSYS pin.

Keep the headerless S2 beside the breadboard with three direct-solder leads ending in male breadboard pins. Do not insert both adjacent header rows into a standard breadboard's connected five-hole strips: that would short different pins together.

On your received converter, oriented like IMG_3222 with the **XL63070 text at the bottom and inductor on the left**: **VOUT top left, GND top right, VIN bottom left, GND bottom right**. The older breadboard illustration rotates this board 90 degrees; follow the printed terminal names. Each power terminal has duplicate holes. Left/right ground pads share a ground net. The received PCB is marked XL63070. Leave EN, PS, ADJ and the voltage-selection pads unchanged while preparing wires. Do not add solder to these small configuration pads. The selected setting must be checked and the output measured at about 5.0 V before connecting the S2 or servo; a product title or 5V marking is not a measurement.

| Wire | From | To |
|---|---|---|
| W1 | Holder red, after its built-in switch | Converter VIN |
| W2 | Holder black | Converter input GND |
| W3 | Converter VOUT, verified 5 V | Left positive rail P48 |
| W4 | Converter output GND | Left ground rail G50 |
| B+ | Positive rail P25 | P26, bridging midpoint break |
| B− | Ground rail G25 | G26, bridging midpoint break |
| W5 | Positive rail P8 | S2 5V/VBUS |
| W6 | Ground rail G10 | S2 GND |
| W7 | S2 GPIO16 | Breadboard j38 |
| W8 | Breadboard i38 | Servo signal, usually orange/yellow |
| W9 | Positive rail P35 | Servo red + |
| W10 | Ground rail G38 | Servo brown/black GND |

P/G numbers count the 50 left rail holes from the top; these are drawing labels, not necessarily printed on your breadboard. Main strips use a–j and rows 1–63. i38 and j38 are joined inside the same five-hole strip. Right-side power rails are unused. All grounds are common. The signal is **3.3 V PWM**, not a 5 V power connection. Never connect a GPIO or 3V3 pin to the 5 V rail.

## Build and verify

1. Remove batteries. Solder holder leads to converter input and two output leads to its output pads. Inspect for solder bridges and add insulation/strain relief without covering hot components. Keep wire strands out of neighboring pads.
2. With power disconnected, check the breadboard rail continuity and its midpoint split. Add the two rail bridges as shown. Verify + and ground are not shorted. Do not use resistance/continuity mode on a powered circuit.
3. Leave S2 and servo disconnected. Install cells with correct polarity, switch on, and measure output with black meter lead in COM and red in V/Ω, DC volts mode. Black probe on ground rail and red on positive rail should read about 5.0 V. If it reads raw battery voltage or another selection such as 9 V, switch off and investigate before connecting anything.
4. Switch off and remove cells before connecting S2/servo. Install only the three identified S2 jumpers and servo connections. Keep USB unplugged. Initial motion must use conservative PWM limits with the horn unloaded; full 180° commands are not the initial test.
5. Watch for resets, jitter, voltage sag and warm contacts/regulator during short tests. A multimeter can miss fast supply dips; passing this check is not proof of transient performance. Do not deliberately stall the servo. Thin jumper leads and breadboard contacts can become the limit before the converter does.

## USB programming — important S2 difference

The [official S2 Mini schematic](https://www.wemos.cc/en/latest/_static/files/sch_s2_mini_v1.0.0.pdf) ties the 5V/VBUS header directly to USB VBUS. **Disconnect the S2's three jumper leads before plugging in USB.** Turning the battery switch off, or unplugging only the battery, is insufficient: USB would otherwise power the servo rail and feed voltage into the converter output.

For a separate live USB/servo test, use the [explicit split-supply mode](https://github.com/eoinest/auto-switch/blob/main/docs/reviews/wiring-decision-2026-09-08.md): remove and insulate the booster-to-S2 VBUS lead, keep ground common, and manage the signal when either device is unpowered. This is different from the isolated programming procedure above.

After programming, unplug USB first, reconnect the three jumpers with battery power off, then switch the battery holder on. Use the dedicated `config.s2-demo.example.json`, not a Pico configuration. GPIO16 is an ordinary output-capable pin on ESP32-S2; PWM support is described in [Espressif's LEDC documentation](https://docs.espressif.com/projects/esp-idf/en/stable/esp32s2/api-reference/peripherals/ledc.html).

## Mechanical prototype

Use the [isolated servo mechanism](https://github.com/eoinest/auto-switch/blob/main/docs/servo-command-mount.md) and the [current combined electronics fit-test print](https://github.com/eoinest/auto-switch/blob/main/hardware/cad/revision-print-v8/README.md). The option C booster mount matches the received board’s approximate outline; bare PCB thickness and contact areas remain unmeasured. Keep solder and wire bends clear of its narrow retaining fingers.

## Reproduce

`python3 tools/render_s2_demo.py` produces both SVG copies, wiring JSON and CSV. `python3 tools/verify_s2_demo.py` independently checks breadboard topology against the required nets. PNG is rasterized from that SVG using the open-source `sharp` package. The static learning page has no hardware API calls.

Physical assembly, servo operation, converter current capacity and mechanical fit remain untested. See [S2 firmware validation](https://github.com/eoinest/auto-switch/blob/main/docs/s2-firmware.md) for the completed USB-only network checks.

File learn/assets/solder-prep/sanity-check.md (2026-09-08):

# Minimum-demo electrical sanity check

Reviewed 2026-09-07 for the headerless ESP32-S2 Mini, received XL63070 module, switched four-AA holder, and one MG90S. No firmware, private configuration, or connected hardware was accessed or changed.

**Verdict: the current power topology is suitable for a short, supervised first bench trial, conditional on voltage and load testing. Its current capacity has not been demonstrated.** Extra power gating, a signal resistor, battery monitoring, WAGO connectors, or a separate rocker are not needed to establish basic operation. This is not approval for an unattended or stall-tolerant installation.

A [fresh three-critic review](https://github.com/eoinest/auto-switch/blob/main/docs/reviews/wiring-decision-2026-09-08.md) adds direct duplicate-hole wiring and the live USB test procedure, including signal sequencing.

## Correct minimum connections

```text
4 × AA alkaline cells
       holder switch
          │ +                        XL63070 VOUT — measured 5 V
          └── VIN [XL63070] VOUT ───────────┬── S2 5V/VBUS
holder − ──── GND         GND ────────┐    └── servo red/+ supply
                                     ├─────── S2 GND
                                     └─────── servo brown/black GND
                                              
                              S2 GPIO16 ────── servo signal
```

The two converter GND terminal groups are the same common ground. The signal is 3.3 V PWM; it is not the servo's power supply. Never connect the 5 V power rail to GPIO16 or 3V3.

The [WEMOS S2 Mini schematic](https://www.wemos.cc/en/latest/_static/files/sch_s2_mini_v1.0.0.pdf) connects VBUS to the USB supply and the onboard 3.3 V regulator input. Its 3V3 net powers the ESP32; it is a different net. The [official pin diagram](https://www.wemos.cc/en/latest/_static/boards/s2_mini_v1.0.0_4_16x9.jpg), viewed component-side with USB down, puts VBUS, GND, GPIO16 in the bottom three positions of the outermost right pad row, read upward. Compare the actual board labels before soldering. [Espressif's LEDC documentation](https://docs.espressif.com/projects/esp-idf/en/stable/esp32s2/api-reference/peripherals/ledc.html) supports routing PWM to an output GPIO.

In the received `IMG_3222.JPG` orientation, **VOUT is upper left, GND upper right, VIN lower left, and GND lower right**. Duplicate holes within each labeled terminal group are alternate solder positions, not additional independent signals. The older map rotates the converter; follow labels rather than page-left/page-right.

## Voltage selection and batteries

The current BOM specifies **four Amazon Basics 1.5 V alkaline cells**, not NiMH and not the earlier LiPo. Their series voltage is approximately 6 V nominal and varies with charge/load. Raw pack voltage goes only to converter VIN. Keep using the buck-boost for this alkaline configuration; a resistor is not a substitute for voltage regulation.

The [selected module's seller information](https://www.amazon.com/dp/B0GCW44FDL) offers 3.3/5/9 V selection links, says to use only one selection, and describes EN as enabled and PWM as the default. Leave EN, PS, and ADJ alone for this trial. **A “5 V” purchase option, board name, or apparent solder bridge is not a voltage measurement.** Before connecting the S2 or servo, check actual VOUT-to-GND with the multimeter. Investigate any output materially different from approximately 5.0 V.

## Current capability: possible, not yet proven

The seller advertises **2 A maximum**, with operating-condition and heating caveats. It does not establish that this particular assembled module can supply 2 A continuously at every input voltage. The chip name alone cannot certify the module's inductor, cooling, soldering, or protection behavior. Do not treat a chip switch-current rating as available 5 V output current.

[TowerPro's MG90S specification](https://towerpro.com.tw/product/mg90s-3/) gives 4.8 V operating information, but does not supply a verified peak/stall-current figure or a 3.3 V signal-high threshold for this user's servo. A regulated 5 V rail and 3.3 V GPIO signal are reasonable first-trial choices, but actual response must be checked. If motion fails while power remains stable, check pulse settings, plug orientation, and signal compatibility; never apply 5 V to an ESP32 GPIO to “fix” it.

Both Wi-Fi transmission and servo starting/changing load can produce short current demands. [Espressif recommends a supply capable of at least 500 mA for the chip's 3.3 V power design](https://docs.espressif.com/projects/esp-hardware-design-guidelines/en/latest/esp32s2/schematic-checklist.html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); that is a supply-design recommendation, not a claim that this assembled board always consumes 500 mA. Its existing onboard regulator and capacitors remain in use.

For illustration only, assuming 85% converter efficiency:

```text
input current ≈ (5 V × output current) / (battery voltage × 0.85)

1 A at the 5 V output → about 0.98 A from a 6 V pack
1 A at the 5 V output → about 1.47 A from a 4 V pack
2 A at the 5 V output → about 2.94 A from a 4 V pack
```

Those are calculation examples, not measured servo demand or a promise of converter performance. Lower battery voltage demands more input current for the same output power. Cell resistance, holder contacts, switch, thin jumpers, and breadboard contacts can cause sag before a headline converter limit is reached. [Energizer's alkaline application manual](https://data.energizer.com/pdfs/alkaline_appman.pdf) documents load-dependent voltage and internal-resistance effects; it is general alkaline behavior, not a test of these Amazon cells.

## Minimum bring-up sequence

1. **No batteries and no USB:** verify polarity, insulation, solder joints, and the actual breadboard's continuity/splits. Use factory male jumper pins or suitable solid wire ends; do not force loose stranded wire into breadboard contacts.
2. **Converter only:** leave S2 and servo disconnected. Measure the switched pack input and converter output. Meter black lead goes in COM, red in V/Ω, meter set to DC voltage—not current. Do not use continuity mode while powered.
3. **S2 alone:** switch off before connecting it, then run from the verified converter supply with USB absent. Confirm Wi-Fi/web serving stays stable.
4. **Add the unloaded servo:** switch off first. Test conservative movements with the horn free from the switch mechanism. Keep the supply wiring short and secure. Stop for jitter, ESP32 resets, visible voltage sag, or heating at cells/contacts/leads/converter. Do not deliberately stall the servo.
5. Only after that succeeds, test gentle mechanical loading. A multimeter can miss rapid dips; “about 5 V” on its display does not rule out brief brownouts. Repeated trouble calls for better power-path measurements/distribution, not longer forced runs.

An added bulk capacitor near the servo can help short transients if testing shows a need; it cannot repair inadequate continuous current or bad contacts. A fuse is useful fault protection, not a requirement for the logic to operate and not a voltage regulator. The minimal unfused trial relies on disconnected-power assembly and supervision; it is not short-circuit protected as a complete system. Fuse selection and permanent wiring protection belong to the later hardware review. No new protective-part shopping list is necessary to start these staged checks.

## USB programming isolation

**Remove all three S2 harness leads before connecting USB.** Turning the holder switch off is insufficient: the S2 VBUS pad is directly connected to USB, so USB could energize the servo rail and the converter's output. Unplug USB before reconnecting the harness, with battery power off. This simple disconnect procedure avoids adding a power-selection circuit for the demo.

## Repository checks and stale text

`python3 tools/verify_s2_demo.py` passed: 12 mapped wires, both rail bridges, one shared signal strip, four required separate nets, and reference pin order. This checks the drawing's intended connectivity, not real board ratings or physical wiring.

`docs/s2-aa-poc.md` correctly specifies three direct-solder S2 leads with male breadboard ends. At review time `learn/s2-aa-poc.html` still incorrectly specified female-to-male S2 leads and said firmware had not been ported/tested. Those page references were corrected in this update: it now uses direct-solder leads and reports completed USB-only network testing. Servo/battery operation remains marked untested.

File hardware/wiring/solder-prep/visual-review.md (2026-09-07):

# Independent visual electrical review

Reviewed the final rendered PNG on 2026-09-07 against the WEMOS S2 Mini reference orientation and the received converter in `IMG_3222.JPG`. **Visual connectivity and pad callouts pass.** This does not establish physical output voltage, current capacity, or completed soldering.

- S2 is component-side up with USB down. Numbered groups 1/2/3 now point to the **outermost right** VBUS/GND/GPIO16 pads. No 5 V wire connects to the left-side 3V3 pad.
- Converter orientation matches the received photo: VOUT upper left, GND upper right, VIN lower left, GND lower right. Each duplicate-hole pair is one terminal group.
- Holder positive reaches VIN only. Converter VOUT reaches the positive distribution rail, then both S2 VBUS and servo supply.
- Converter output ground reaches the ground rail, S2 ground, and servo ground. Input ground returns to the battery through the converter's common ground.
- GPIO16 reaches only the separate signal strip and servo signal. The diagram distinguishes the servo's power, ground, and control conductors.
- Both split power rails have bridges. Junction dots mark intended joins; white gaps distinguish unconnected crossings.
- The diagram says to measure approximately 5 V with S2/servo disconnected, disconnect cells before soldering, and remove all three S2 leads before USB programming.

The first render had misleading S2 number badges on the left edge, plus overlapping text and an obscured converter badge. Those were corrected and the updated image was re-inspected before this pass.

Reviewed artifact SHA-256:

```text
solder-prep.png  5f71e5a129449d486711235d07ac3915ccbd115dc266f8906b056849f6d2645d
solder-prep.svg  914f57028790ba6947ba114a40345ea6d4aa9893d64c957def613a478b713188
```

This review is independent of the programmatic net checker. Actual breadboard connectivity and board labels must still be confirmed on the user's hardware.

Final legend-only addition: the primary agent visually rechecked the map after adding the instruction to leave configuration pads untouched. Wiring and pad locations were unchanged. Published artifact SHA-256:

```text
solder-prep.png  709a9415d0c53602c3038caa827d65ff73b01af623f72820c5afb164a422c245
solder-prep.svg  39d16859942059eed66736c98539c08de2ce11feec2b754a83754fca018877f9
```

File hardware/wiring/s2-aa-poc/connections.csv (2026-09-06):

id | from | to | net | note
W1 | BAT.red | REG.VIN | BAT+ | Holder red → converter VIN; solder connection
W2 | BAT.black | REG.GND_IN | GND | Holder black → converter input GND; solder connection
W3 | REG.VOUT | P48 | 5V | Converter VOUT → left + rail hole 48
W4 | REG.GND_OUT | G50 | GND | Converter output GND → left − rail hole 50
B+ | P25 | P26 | 5V | Bridge positive rail midpoint: P25 → P26
B− | G25 | G26 | GND | Bridge ground rail midpoint: G25 → G26
W5 | P8 | S2.VBUS | 5V | Left + rail hole 8 → S2 outer-right bottom pin 5V/VBUS
W6 | G10 | S2.GND | GND | Left − rail hole 10 → S2 outer-right second pin from bottom GND
W7 | S2.GPIO16 | j38 | PWM | S2 GPIO16 → breadboard j38
W8 | i38 | SERVO.S | PWM | Breadboard i38 → servo signal; i38 and j38 share the same strip
W9 | P35 | SERVO.V+ | 5V | Left + rail hole 35 → servo red power pin
W10 | G38 | SERVO.GND | GND | Left − rail hole 38 → servo brown/black ground pin

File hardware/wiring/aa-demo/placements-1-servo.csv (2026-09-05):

item | from | to | note
D1 | a30 | a35 | Stripe toward row 35 (VSYS).
R_PWM0 | f30 | f35 | 1 kΩ
J1 | b35 | j4 | VSYS
J2 | b50 | j5 | GND
J3 | j22 | j30 | PWM0_RAW
L1 | b30 | P5V.3 | Pico supply branch only; servo current stays off breadboard.
L2 | a50 | PGND_B.2 | Common ground branch to breadboard.
L3 | j35 | SERVO0.signal | Servo 0 signal only.
E1 | BAT.red | F1.in | external harness
E2 | F1.out | RCY.battery_positive | external harness
E3 | RCY.battery_positive | RCY.load_positive | external harness
E4 | RCY.load_positive | MASTER.VIN | external harness
E5 | MASTER.VOUT | REG.VIN | external harness
E6 | REG.VOUT | P5V.1 | external harness
E7 | P5V.2 | C1.positive | external harness
E8 | P5V.4 | SERVO0.power | external harness
E9 | BAT.black | RCY.battery_negative | external harness
E10 | RCY.battery_negative | RCY.load_negative | external harness
E11 | RCY.load_negative | PGND_A.1 | external harness
E12 | PGND_A.2 | MASTER.GND | external harness
E13 | PGND_A.3 | REG.GND | external harness
E14 | PGND_A.4 | PGND_B.1 | external harness
E15 | PGND_A.5 | C1.negative | external harness
E16 | PGND_B.3 | SERVO0.ground | external harness

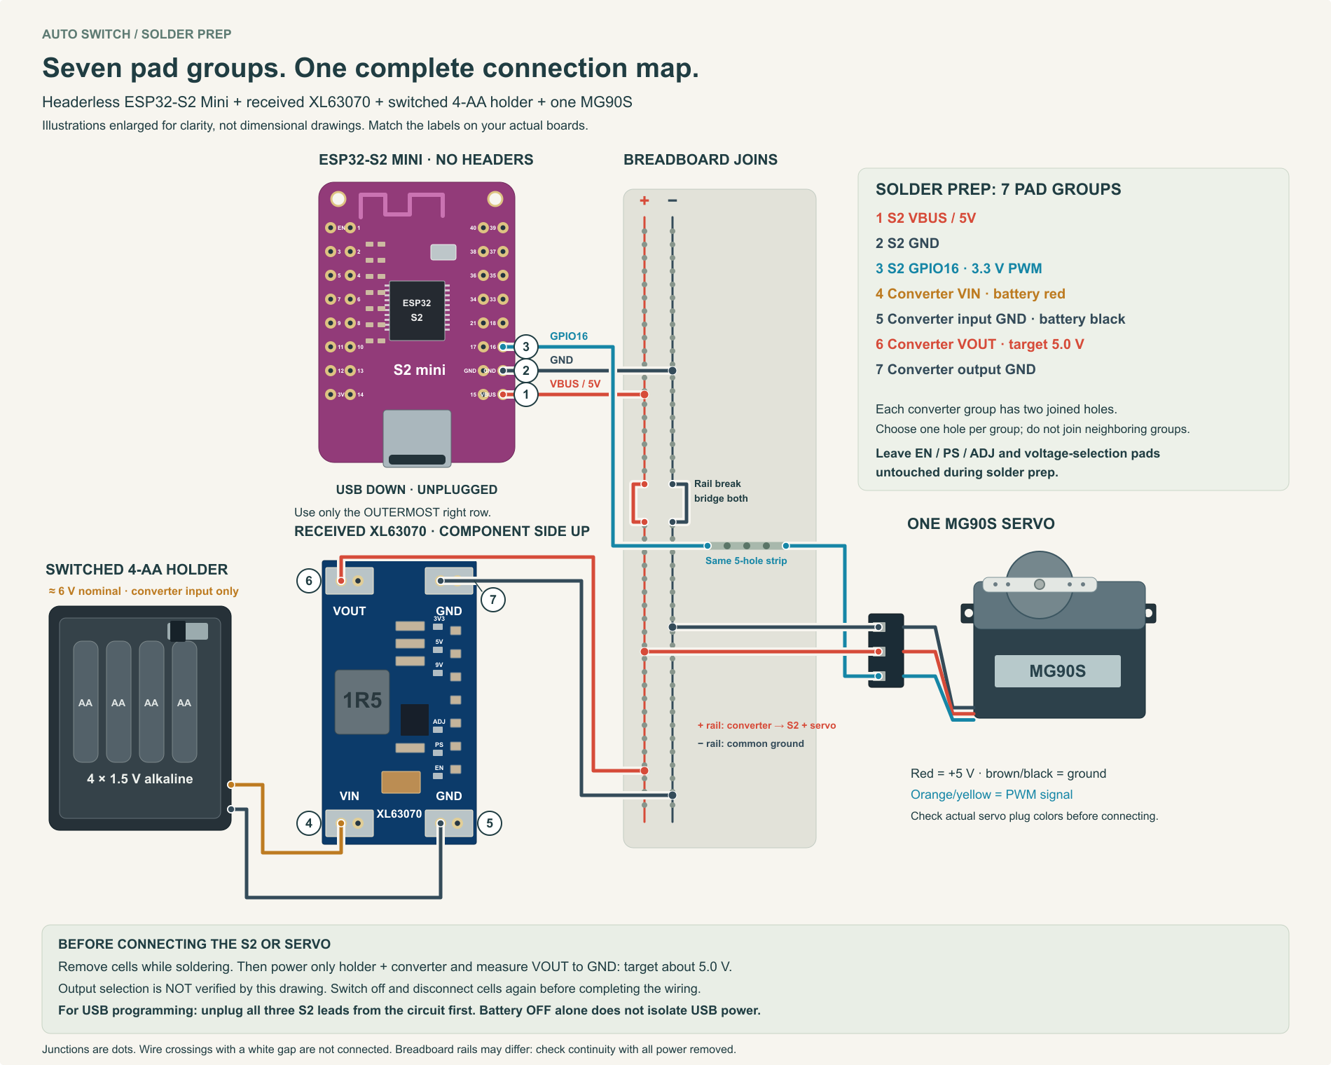
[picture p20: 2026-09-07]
learn/assets/solder-prep/solder-prep.png

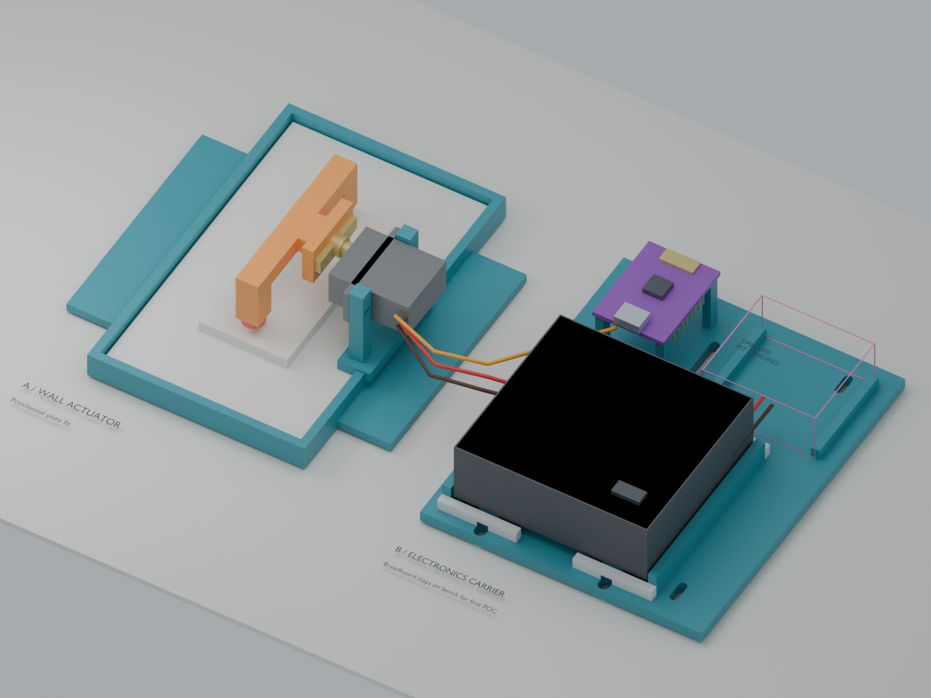
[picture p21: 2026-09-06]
learn/assets/s2-aa-poc/assembly-preview.png

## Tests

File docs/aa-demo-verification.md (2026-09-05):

# AA demo verification — 2026-09-05

Current scope: **one servo only**. The viewer, shopping quantities and firmware example use this build. Two-servo generator outputs remain as prior design references, outside the current shopping/build instructions.

One-servo update checks: 32 AA diagram/BOM tests passed; JavaScript syntax and learning-asset checks passed. Browser inspection confirmed one fixed build, four assembly steps, 24 BOM rows, and one-servo download targets. The PNG was regenerated from the updated SVG and visually inspected.

Previous delivery checks (before narrowing the viewer to one servo):

Delivered: Amazon-first bench BOM, one/two-servo component illustrations (SVG and PNG), exact-hole placement CSVs, a local viewer with shopping links, and an explicit ungated firmware profile. The prior gated circuit remains available and labeled as earlier work. No hardware was purchased or powered, and no STL enclosure changes were made.

## Checks completed

- Independent conductor/strip graph: one-servo 41 terminals, 8 nets, 53 occupied breadboard holes, 12/15 WAGO ports used; two-servo 47 terminals, 10 nets, 58 occupied holes, 14/15 ports used.
- Actual SVG verification: 22 wire paths for one servo, 26 for two; all 630 terminal holes, 40 Pico header squares, component endpoints, WAGO ports, conductor geometry, and exported placement tables agree. Mutations test shorts, opens, wrong pins, extra/missing paths, transformed geometry and misleading terminal crossings.
- Firmware fake-hardware checks: AA profile never touches GP15 or the absent battery ADC; legacy gated operation, calibration guards, and cleanup remain covered. PWM shutdown is not claimed to disconnect servo power.
- Purchasing counts checked against one/two-servo circuit quantities, and viewer asset copies checked against their source files.
- Browser: 24 BOM rows and six distinct Amazon purchase links; one/two-servo selection; fit/zoom; enter/exit fullscreen; SVG/PNG/checklist downloads returned successfully; 390 × 844 phone viewport had no page-level horizontal overflow. No page JavaScript errors occurred during the successful flow.
- Visually inspected full-resolution component diagrams and desktop/phone screenshots. Pololu top-view references were inspected for regulator and master terminal orientation. Photographic/cosmetic component details are simplified illustrations, not manufacturing drawings.

The initial complete test run was prevented from binding a local HTTP test socket by the sandbox. Re-running with local execution permission passed. A browser test-script URL-construction issue was corrected; it was not an application failure. Duplicate shopping links and two ambiguous drawn wire routes were corrected before the final checks.

## Reproduce

```sh
python3 tools/render_aa_demo.py
python3 tools/verify_aa_demo.py
python3 tools/build_aa_demo.py
python3 -m unittest discover -s tests -p 'test_*.py'
python3 tools/build_learning.py --check
node --check learn/aa-demo.js
```

PNG files were exported from each final SVG using Chromium at its native 2480 × 1900 size. After changing vector geometry, re-export both PNGs before running `build_aa_demo.py`; that script copies PNGs rather than re-rendering them. Browser inspection screenshots are local ignored artifacts in `output/playwright/`.

## Limits

Connectivity checking does not simulate a circuit or certify solder joints, breadboard contact fit, battery depletion behavior, current capability, servo torque, or voltage transients. The complete assembly still needs the voltage and loaded-operation checks in [the guide](aa-demo-plan.md). Existing STL fit evidence does not apply to the new WAGO/breadboard assembly. Amazon checks establish listing identity, not delivered authenticity, checkout price, or inventory; see [the source record](aa-demo-source-checks.md).

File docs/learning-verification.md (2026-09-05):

# Learning module verification — 2026-09-05

The learning module uses the claim/source registry in [learn-sources.md](learn-sources.md). These checks validate software behavior and selected nominal geometry; they do not certify a physical circuit or assembly.

- 51 Python tests passed, including firmware, relay, wiring contracts, curriculum references, generated learning assets and BOM evidence.
- JavaScript model checks passed for all 16 supply/master/request combinations, resistance/current units, ADC limits, energy assumptions and capacitor depletion.
- Browser checks passed for USB-only motor isolation; both-source operation; master-off highlighting; wrong answers, retries and saved lesson progress; all five experiment controls; and correct/incorrect design challenge scoring.
- BOM search, one/two-servo quantities and installed print quantities worked in the browser. Local reference links resolved.
- Desktop, dark-mode and phone layouts were inspected. Power, lessons, workbench and parts pages had no document-width overflow at 320 px; detailed diagrams and tables intentionally scroll within their containers. The browser reported no console errors or warnings.
- Direct `file://` navigation was blocked by the browser automation tool, so that launch method was not browser-verified. The tested localhost version uses bundled local assets without fetching course data or calling hardware APIs. External reference and purchase links require internet access.
- All 21 STL files passed independent manifold, positive-volume, print-bed and A1 build-volume checks. The [BOM fit report](bom-fit-report.md) records 13 checks against current exported meshes and component models. Hash checks bind that evidence to the current BOM, models and STL files.

The remaining physical measurements, unselected horn fasteners and textured-wall attachment are explicit in the [BOM](../BOM.md). No hardware power, motion, battery-runtime or physical fit testing has been performed by these software checks.

## Continuous-map revision

The former panel-based connection sheet is replaced by one continuous circuit and a dedicated default Connection map tab. All 46 visible terminals have the correct net assignments and lie on actual SVG wire segments. Each of 13 nets is one connected segment graph; no unrelated nets have collinear overlaps or junction dots on each other. Seven learning/bundle/diagram tests pass. Browser checks cover zoom, fit-to-view, fullscreen entry/exit and fitting the entire map at both desktop and phone viewport sizes.

## Breadboard bench layout

The added 63-row breadboard plan places a headered Pico W at c3–c22/h3–h22. Ten independent tests check conductive strips, one/two-servo net equivalence, all 40 header positions, unused-pin isolation, duplicate hole occupancy, deliberate wiring errors, and actual rendered insertion markers/CSV addresses. Both profiles pass: 40 terminals across 11 nets for one servo; 46 across 13 nets for two. Browser checks cover step highlighting, 18/21 checklist rows, profile switching, fit/zoom/fullscreen and phone-width overflow. Source references and unpowered/voltage-check procedures are in the breadboard guide. This is an electrically checked design, not a bench-tested circuit or a fit check for the printed enclosure.

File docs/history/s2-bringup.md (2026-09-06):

# Historical S2 Mini bring-up notes

This records the earlier provisioning and gateway experiments. For the current
standalone, two-button POC, follow [the S2 firmware guide](../s2-firmware.md).
The gateway and daily/check-in modes below are not the current build.

Use `firmware/config.s2-demo.example.json` for the headerless ESP32-S2 Mini.
The `s2-demo` profile requires exactly one channel on GPIO16, no servo power
gate and no battery ADC. Both direct HTTP and Mac gateway transports are
supported. The example defaults to **direct transport**, with `open_client: true`:
the ESP32 serves the two-button **On / Off** website itself on port 80 and keeps
Wi-Fi active. No Mac gateway, mode selector or check-in interval is needed.
Movement remains disabled and uncalibrated. Sample pulse widths are not calibrated endpoints.

## Installed board

On 2026-09-05, esptool identified the connected board as ESP32-S2FNR2,
4 MB flash and 2 MB embedded PSRAM. A complete 4,194,304-byte original flash
backup was saved locally before erasing. Official
[LOLIN S2 Mini MicroPython v1.29.0](https://micropython.org/download/LOLIN_S2_MINI/)
was installed at offset `0x1000`; esptool verified the written data hash.
The board subsequently reported the LOLIN_S2_MINI build through its USB REPL.

Private Wi-Fi credentials, client/device tokens, flash backup and test logs
are in the Git-ignored `.local/s2/` directory. Never publish that directory.
`config.json` on the board contains its Wi-Fi password (and access tokens if
authenticated direct access or gateway transport is configured).

## Transfer or update

Keep the board disconnected from the battery/servo harness during USB setup.
The S2 Mini's VBUS pad connects directly to USB power; switching off the battery
alone does not isolate the servo rail. See [wiring precautions](../s2-aa-poc.md).

1. Fill a private copy of the S2 example with your Wi-Fi credentials. Keep
   `transport: "direct"` and `open_client: true` for the standalone demo.
   For authenticated browser access, use `open_client: false` and set a random
   24–128-character `api_token`. Credentials belong only in the ignored private copy.
2. Copy the six Python modules and the private configuration with `mpremote`:

```sh
mpremote fs cp firmware/control.py firmware/hardware.py firmware/http_api.py firmware/gateway_client.py firmware/bench.py firmware/main.py :
mpremote fs cp .local/s2/config.json :config.json
```

For direct transport also copy the three static assets to `/www/` before reset:

```sh
mpremote fs mkdir :www
mpremote fs cp firmware/www/index.html firmware/www/app.js firmware/www/style.css :www/
mpremote reset
```

Skip `mkdir` if the directory already exists. The USB console prints the board's
address as `auto-switch UI: http://...`. The S2 example also sets
`hostname: "auto-switch"` before Wi-Fi starts. Official ESP32 MicroPython's
[built-in mDNS responder](https://github.com/micropython/micropython/blob/v1.29.0/ports/esp32/network_wlan.c#L180-L195)
makes `http://auto-switch.local/` available on networks
and clients that support local multicast discovery. On the same Wi-Fi, use
that name or the printed numeric address on your phone; neither needs `:8768`.
Use a different hostname for each additional switch to avoid name collisions. `/api/access` lets the page discover
whether it should connect immediately or request a key. Open access applies only
to the explicitly selected S2 direct-demo profile. It does not bypass the enabled
and calibrated channel checks. A battery supply can replace USB after bring-up;
the Mac is not part of the direct control path.

### Optional ESP32 transmit-power diagnostic

The private `wifi` object may include `"txpower_dbm": 8.5` to reduce radio
transmit power during troubleshooting. Firmware applies it after activating
Wi-Fi and before connecting. This ESP32-only setting accepts finite numeric
values from 2 through 20 dBm; omit it to retain the platform default. It may
reduce Wi-Fi range. A successful connection at reduced transmit power does
**not** prove the USB cable or battery power supply is healthy, nor establish
battery life. The public example leaves this diagnostic setting unset.

## Optional legacy gateway transport

To use the Mac gateway again, set `transport: "gateway"`, `open_client: false`
and configure `gateway.host`, `gateway.port` and `gateway.token` in the private
configuration. Reserve the Mac's address in the router or update the host setting
when it changes. Gateway mode serves the website from the Mac; it does not expose
a second web server on the board.

The local bring-up gateway uses port 8768. Its private restart helper is
`python3 .local/s2/run-gateway.py`; stop the existing gateway before restarting.
The local prototype helper selects `--demo-only --open-client`. The website
shows only **On** and **Off**, and the gateway keeps the board in responsive
demo mode on every poll. `--demo-only` also replaces a saved daily-mode setting
and rejects API requests to enable check-in mode. It is distinct from `--demo`,
which simulates hardware. No channel is enabled or calibrated by this option.

With `--open-client`, the website opens
directly without asking for a key. Anyone who can reach this gateway can read
status and send control requests. This is a local-network convenience mode;
it does not create a public URL or change router settings. Device poll/ack
requests still require the private device token, and disabled or uncalibrated
channels still cannot move.

The gateway defaults to authenticated browser access. Remove `--open-client`
from the private helper and restart to restore the client-key prompt; the saved
client token remains in `.local/s2/client-token.txt`. For other launchers, opt in
explicitly with `python3 gateway/server.py --open-client --host 0.0.0.0` and supply
`AUTO_SWITCH_DEVICE_TOKEN` through the environment. A client token is optional
in this mode. Keep this prototype on the trusted LAN; do not forward its port.
The Mac must remain running and reachable for gateway control.

## Validation scope

The USB-connected S2 now serves the direct HTTP API on port 80. Both its
numeric LAN address and `auto-switch.local` returned HTTP 200 with
`transport: direct`, `platform: esp32`, and increasing uptime. The three served
UI assets matched the repository files byte for byte. This bring-up used the
optional 8.5 dBm transmit-power setting after intermittent USB connections;
the cause of those interruptions is not established. Servo channels remain
disabled and uncalibrated.

The following observations describe earlier gateway testing:

The real board joined Wi-Fi, synchronized its clock and sent authenticated
status with `hardware_profile: s2-demo`, `platform: esp32`, `battery: null`
and `servo_power_gated: false`. The default gateway rejects unauthenticated
status requests; the opt-in open-client mode accepts them. Both modes reject
movement requests for the disabled channel. Status also includes
MicroPython's numeric `reset_cause` to diagnose restarts.

Demo mode requests a one-second delay between completed polls; network overhead
adds to the interval. Daily mode disables Wi-Fi between polls, but does not put
the CPU into deep sleep or disconnect servo power. No battery-life claim follows
from these software modes.

During USB-only testing, demo check-ins arrived about every 1.8–1.9 seconds
and uptime increased continuously during a one-minute observation. Switching
to daily mode with a 10-second interval reproduced a restart, including with
no serial connection open. The next boot reported reset cause `1` (power-on);
the cause of the reset is not yet established. Daily mode is **not validated
on this board**. The gateway was returned to demo mode. Check USB power/cable
and the board's power behavior before using radio-off operation.

The firmware and gateway tests cover both authenticated and open-client access,
including authenticated device check-ins and movement guards. The broader suite
also reports a pre-existing stale BOM audit for the separately modified
`hardware/cad/generated/auto-switch.blend`; that model was not changed by
firmware provisioning.

Servo movement, PWM waveform, electrical assembly, battery operation and
mechanical fit have not been tested on this board. Leave `enabled` and
`calibrated` false until the assembled actuator has been calibrated.

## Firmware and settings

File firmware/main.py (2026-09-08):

"""Copy with companion modules to Pico W or S2 Mini running MicroPython."""
import json
import time
import sys
import uasyncio as asyncio
from control import Controller, Scheduler
from calibration import load_calibration, save_calibration
from hardware import Hardware
from http_api import API, client_access
from gateway_client import GatewayClient, validate_poll, process_commands


def configure_hostname(network, config):
    """Set the optional local network name before Wi-Fi starts."""
    hostname = config.get("hostname")
    if hostname is None:
        return
    if (not isinstance(hostname, str) or not 1 <= len(hostname) <= 63
            or hostname[0] == "-" or hostname[-1] == "-"
            or any(c not in "abcdefghijklmnopqrstuvwxyz0123456789-" for c in hostname)):
        raise ValueError("hostname must be 1-63 lowercase ASCII letters, digits or internal hyphens")
    network.hostname(hostname)


class Clock:
    def __init__(self):
        self.previous = time.ticks_ms()
        self.elapsed_ms = 0
        self.last_sync_ms = None
        self.next_sync_ms = 0

    def tick(self):
        current = time.ticks_ms()
        self.elapsed_ms += time.ticks_diff(current, self.previous)
        self.previous = current

    def synced(self):
        return self.last_sync_ms is not None and self.elapsed_ms - self.last_sync_ms < 86400000

    def sync(self):
        if self.elapsed_ms < self.next_sync_ms:
            return
        self.next_sync_ms = self.elapsed_ms + 60000
        try:
            import ntptime
            ntptime.timeout = 2
            ntptime.settime()
            if 2024 <= time.localtime()[0] <= 2099:
                self.last_sync_ms = self.elapsed_ms
                self.next_sync_ms = self.elapsed_ms + 21600000
        except Exception:
            print("NTP unavailable; schedules need a recent successful UTC sync")


def wifi_txpower(wifi):
    """Optional ESP32 radio diagnostic setting; retain platform defaults otherwise."""
    if "txpower_dbm" not in wifi:
        return None
    value = wifi["txpower_dbm"]
    if sys.platform != "esp32":
        raise ValueError("wifi.txpower_dbm is only supported on ESP32")
    if type(value) not in (int, float) or not 2 <= value <= 20:
        raise ValueError("wifi.txpower_dbm must be a finite number from 2 to 20")
    return value


async def connect(wlan, wifi):
    txpower = wifi_txpower(wifi)
    if wlan.isconnected():
        return
    wlan.active(True)
    if txpower is not None:
        wlan.config(txpower=txpower)
    wlan.connect(wifi["ssid"], wifi["password"])
    for _ in range(60):
        if wlan.isconnected():
            return
        await asyncio.sleep(0.2)
    wlan.active(False)
    raise OSError("WiFi connection timed out")


async def maintain_clock_and_schedules(clock, scheduler, controller):
    while True:
        clock.tick()
        for entry in scheduler.due(time.localtime(), clock.synced()):
            try:
                # Network housekeeping uses the same guard because DNS/NTP
                # may block the interpreter. A due local event waits for it.
                while controller.lock.locked():
                    await asyncio.sleep(0.05)
                await controller.move(entry["channel"], entry["state"])
            except Exception as error:
                print("Schedule skipped:", str(error))
        await asyncio.sleep(1)


async def run(config, hardware=None):
    hardware = hardware if hardware is not None else Hardware(config)
    import machine
    reset_cause = machine.reset_cause()
    scheduler_task = None
    try:
        controller = Controller(config, hardware, persist=save_calibration)
        scheduler = Scheduler(config.get("schedules_utc", []), len(controller.channels))
        clock = Clock()
        transport = config.get("transport", "direct")
        if transport not in ("direct", "gateway"):
            raise ValueError("transport must be direct or gateway")
        try:
            import network
            configure_hostname(network, config)
            if config.get("hardware_profile") == "s2-demo":
                network.WLAN(network.WLAN.IF_AP).active(False)
            wlan = network.WLAN(network.STA_IF)
        except (ImportError, AttributeError):
            print("No WiFi hardware: use USB REPL import bench; bench.move(0, 'on')")
            return

        def status():
            clock.tick()
            return {"device": config.get("device", "auto-switch"),
                    "channels": controller.status_channels(), "battery": hardware.battery(),
                    "uptime": clock.elapsed_ms // 1000, "clock_synced": clock.synced(),
                    "busy": controller.busy, "transport": transport,
                    "calibration": controller.calibration_status(),
                    "calibration_available": config.get("hardware_profile") == "s2-demo" and transport == "direct",
                    "hardware_profile": config.get("hardware_profile", "gated"),
                    "platform": sys.platform, "reset_cause": reset_cause,
                    "servo_power_gated": controller.power_enable_pin is not None}

        # Validate credentials before starting schedules or network operations.
        open_client = client_access(config)
        client = GatewayClient(config["gateway"]) if transport == "gateway" else None
        api = API(controller, status, config.get("api_token", ""),
                  open_client=open_client) if client is None else None
        wifi = config["wifi"]
        if not wifi.get("ssid"):
            raise ValueError("set wifi.ssid in config.json")
        scheduler_task = asyncio.create_task(maintain_clock_and_schedules(clock, scheduler, controller))
        if transport == "direct":
            while True:
                try:
                    async with controller.lock:
                        await connect(wlan, wifi)
                        clock.sync()
                    break
                except OSError as error:
                    print(str(error))
                    await asyncio.sleep(15)
            server = await asyncio.start_server(api.handle, "0.0.0.0", 80, backlog=2)
            print("auto-switch UI: http://" + wlan.ifconfig()[0])
            try:
                while True:
                    try:
                        async with controller.lock:
                            await connect(wlan, wifi)
                            clock.sync()
                    except OSError:
                        pass
                    await asyncio.sleep(30)
            finally:
                server.close()
                await server.wait_closed()
        else:
            mode, interval = "daily", 60
            while True:
                try:
                    async with controller.lock:
                        await connect(wlan, wifi)
                        clock.sync()
                        payload = await client.post("/api/device/poll", {"status": status()})
                    validate_poll(payload, len(controller.channels))
                    mode = payload["mode"]
                    interval = 1 if mode == "demo" else payload["poll_interval_s"]
                    await process_commands(payload, controller, client, status)
                except Exception as error:
                    print("Gateway poll failed:", str(error))
                    mode, interval = "daily", 30
                # Only Controller owns servo power during runtime; a local
                # schedule may be running while this transport becomes idle.
                if mode == "daily":
                    async with controller.lock:
                        wlan.disconnect()
                        wlan.active(False)
                await asyncio.sleep(interval)
    finally:
        if scheduler_task is not None:
            scheduler_task.cancel()
            try:
                await scheduler_task
            except BaseException:
                pass
        hardware.off()


async def supervise(config, hardware):
    if config.get("hardware_profile") != "s2-demo" or config.get("transport", "direct") != "direct":
        return await run(config, hardware)
    import machine
    import maintenance
    button = machine.Pin(0, machine.Pin.IN, machine.Pin.PULL_UP)
    hold = maintenance.BootHold()
    task = asyncio.create_task(run(config, hardware))
    try:
        while True:
            if hold.update(button.value(), time.ticks_ms()):
                hardware.inhibit()
                if task is not None:
                    task.cancel()
                    try:
                        await task
                    except BaseException:
                        pass
                    task = None
                hardware.off()
                # Remove a legacy WebREPL listener if an older boot.py started it.
                if "webrepl" in sys.modules:
                    sys.modules["webrepl"].stop()
                await maintenance.run(config, connect)
                return
            if task is not None and task.done():
                try:
                    await task
                except Exception:
                    print("Application stopped; hold BOOT/0 for update recovery")
                task = None
                hardware.off()
            await asyncio.sleep(0.05)
    finally:
        hardware.inhibit()
        if task is not None:
            task.cancel()
            try:
                await task
            except BaseException:
                pass
        hardware.off()


def start():
    hardware = None
    try:
        with open("config.json") as stream:
            config = json.load(stream)
        load_calibration(config)
        hardware = Hardware(config)
        asyncio.run(supervise(config, hardware))
    except OSError as error:
        print("Startup stopped. Copy/edit config.example.json as config.json:", str(error))
    except Exception as error:
        print("Startup stopped; disconnect servo supply before troubleshooting:", str(error))
    finally:
        # KeyboardInterrupt can escape the event-loop poll without unwinding a
        # suspended coroutine on MicroPython. Clean up synchronously before REPL.
        if hardware is not None:
            hardware.off()


if __name__ == "__main__":
    start()

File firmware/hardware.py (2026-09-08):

"""Pico/S2 hardware boundary with explicit gated and powered demo profiles."""
from machine import ADC, Pin, PWM
from control import battery_reading, validate_hardware_config


class Hardware:
    def __init__(self, config):
        enable_pin = validate_hardware_config(config)
        self.enable = Pin(enable_pin, Pin.OUT, value=0) if enable_pin is not None else None
        self.pins = [c["pin"] for c in config["channels"]]
        self.pwms = {}
        self.inhibited = False
        for pin in self.pins:
            Pin(pin, Pin.OUT, value=0)
        self.battery_cfg = config.get("battery", {})
        self.adc = ADC(26) if self.battery_cfg.get("enabled") is True else None

    def power_on(self):
        if self.inhibited:
            raise RuntimeError("servo disabled in update mode")
        # The AA demo rail is already powered; this cannot switch it.
        if self.enable is not None:
            self.enable.value(0)
        reading = self.battery()
        if reading is not None and reading["low"]:
            raise ValueError("battery below low_v; recharge before moving")
        if self.enable is not None:
            self.enable.value(1)

    def pulse(self, channel, microseconds):
        if self.inhibited:
            raise RuntimeError("servo disabled in update mode")
        if channel not in self.pwms:
            self.pwms[channel] = PWM(Pin(self.pins[channel]), freq=50, duty_u16=0)
        self.pwms[channel].duty_ns(microseconds * 1000)

    def inhibit(self):
        """Latch until reboot so already accepted HTTP tasks cannot restart PWM."""
        self.inhibited = True
        self.off()

    def off(self):
        # Gated profile cuts the rail first. AA demo only stops control pulses;
        # it cannot guarantee loss of holding torque or remove servo power.
        if self.enable is not None:
            self.enable.value(0)
        for pwm in self.pwms.values():
            pwm.duty_u16(0)
            pwm.deinit()
        self.pwms = {}
        for pin in self.pins:
            Pin(pin, Pin.OUT, value=0)

    def battery(self):
        if self.adc is None:
            return None
        raw = sum(self.adc.read_u16() for _ in range(8)) // 8
        return battery_reading(raw, self.battery_cfg)

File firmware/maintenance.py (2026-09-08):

"""BOOT-held browser updates on saved home Wi-Fi only."""
import binascii
import gc
import hashlib
import json
import os
import time
try:
    import uasyncio as asyncio
except ImportError:
    import asyncio
from http_api import read_headers, token_matches

FILES = ('control.py', 'calibration.py', 'hardware.py', 'http_api.py',
         'gateway_client.py', 'bench.py', 'main.py', 'maintenance.py',
         'www/index.html', 'www/app.js', 'www/style.css', 'www/update.html')
MAGIC = b'AUTOSWITCH1\n'
MAX_BUNDLE = 512 * 1024
MAX_FILE = 64 * 1024


class BootHold:
    def __init__(self):
        self.armed = False
        self.since = None

    def update(self, value, now):
        if value:
            self.armed = True
            self.since = None
        elif self.armed:
            if self.since is None:
                self.since = now
            elif time.ticks_diff(now, self.since) >= 3000:
                self.armed = False
                return True
        return False


def credentials():
    import maintenance_cfg
    value = maintenance_cfg.PASSWORD
    if not isinstance(value, str) or not 24 <= len(value) <= 63 or not value.isalnum():
        raise ValueError('invalid private update password')
    if any(ord(c) > 127 for c in value):
        raise ValueError('invalid private update password')
    return value


async def choose_network(config, connect):
    import network
    # Explicitly disable AP mode even if an older firmware left it active.
    network.WLAN(network.WLAN.IF_AP).active(False)
    sta = network.WLAN(network.WLAN.IF_STA)
    try:
        await asyncio.wait_for(connect(sta, config['wifi']), 15)
        if sta.isconnected():
            return sta
    except (OSError, ValueError, asyncio.TimeoutError):
        pass
    return None


class BundleStream:
    def __init__(self, reader, length):
        self.reader, self.remaining = reader, length

    async def take(self, count):
        if count > self.remaining:
            raise ValueError('truncated bundle')
        result = bytearray()
        while len(result) < count:
            data = await self.reader.read(count - len(result))
            if not data:
                raise ValueError('truncated bundle')
            result.extend(data)
        self.remaining -= count
        return bytes(result)

    async def line(self):
        result = bytearray()
        while not result.endswith(b'\n'):
            if len(result) >= 256:
                raise ValueError('oversized record')
            result.extend(await self.take(1))
        return bytes(result)


def stage_path(index):
    return '.update-' + str(index)


def verify_staged(index, digest, name):
    sha = hashlib.sha256()
    path = stage_path(index)
    with open(path, 'rb') as stream:
        while True:
            data = stream.read(1024)
            if not data:
                break
            sha.update(data)
    if binascii.hexlify(sha.digest()).decode() != digest:
        raise ValueError('file verification failed')
    if name.endswith('.py'):
        gc.collect()
        with open(path) as stream:
            compile(stream.read(), name, 'exec')
        gc.collect()


async def stage_bundle(reader, length):
    if not 0 < length <= MAX_BUNDLE:
        raise ValueError('invalid bundle size')
    stream = BundleStream(reader, length)
    if await stream.take(len(MAGIC)) != MAGIC:
        raise ValueError('wrong bundle format')
    seen = set()
    while True:
        header = json.loads(await stream.line())
        if header == {'end': True}:
            if stream.remaining or seen != set(FILES):
                raise ValueError('incomplete or trailing bundle')
            return
        if not isinstance(header, dict) or set(header) != {'path', 'size', 'sha256'}:
            raise ValueError('invalid file record')
        name, size, digest = header['path'], header['size'], header['sha256']
        if not isinstance(name, str) or name not in FILES or name in seen:
            raise ValueError('unexpected or duplicate file')
        if type(size) is not int or not 0 < size <= MAX_FILE:
            raise ValueError('invalid file size')
        if not isinstance(digest, str) or len(digest) != 64 or any(c not in '0123456789abcdef' for c in digest):
            raise ValueError('invalid digest')
        index = FILES.index(name)
        with open(stage_path(index), 'wb') as output:
            remaining = size
            while remaining:
                chunk = await stream.take(min(1024, remaining))
                output.write(chunk)
                remaining -= len(chunk)
                await asyncio.sleep(0)
        if await stream.take(1) != b'\n':
            raise ValueError('missing file boundary')
        verify_staged(index, digest, name)
        seen.add(name)


def activate():
    # LittleFS rename-overwrite is atomic for each file, not for the full bundle.
    # Keep main last; USB is still the recovery path for failed activation.
    order = [name for name in FILES if name != 'main.py'] + ['main.py']
    for name in order:
        os.rename(stage_path(FILES.index(name)), name)
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

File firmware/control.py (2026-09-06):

"""Portable safety and scheduling logic; no hardware imports on a host."""
import time
try:
    import uasyncio as asyncio
except ImportError:
    import asyncio


def integer(value, low, high, label):
    if type(value) is not int or not low <= value <= high:
        raise ValueError("invalid " + label)
    return value


def validate_channel(channel):
    for field in ("on_us", "off_us", "neutral_us"):
        integer(channel.get(field), 1100, 1900, field)
    if max(channel[k] for k in ("on_us", "off_us", "neutral_us")) - min(
        channel[k] for k in ("on_us", "off_us", "neutral_us")
    ) > 400:
        raise ValueError("pulse span exceeds 400 us; redesign travel")
    if not min(channel["on_us"], channel["off_us"]) < channel["neutral_us"] < max(channel["on_us"], channel["off_us"]):
        raise ValueError("neutral must lie between on and off")
    integer(channel.get("dwell_ms"), 50, 400, "dwell_ms")
    integer(channel.get("return_ms"), 50, 400, "return_ms")
    integer(channel.get("pin"), 0, 22, "servo pin")


def validate_hardware_config(config):
    """Validate before touching GPIO; return the gate pin or None."""
    profile = config.get("hardware_profile", "gated")
    if profile == "gated":
        enable_pin = config.get("power_enable_pin", 15)
        if type(enable_pin) is not int or enable_pin != 15:
            raise ValueError("gated profile requires power_enable_pin 15")
    elif profile == "aa-demo":
        enable_pin = config.get("power_enable_pin")
        if enable_pin is not None:
            raise ValueError("aa-demo requires power_enable_pin null; GP15 is unused")
        if config.get("battery", {}).get("enabled", False) is not False:
            raise ValueError("aa-demo has no battery ADC; battery.enabled must be false")
        if config.get("transport", "direct") != "direct":
            raise ValueError("aa-demo requires direct transport")
    elif profile == "s2-demo":
        enable_pin = config.get("power_enable_pin")
        if enable_pin is not None:
            raise ValueError("s2-demo requires power_enable_pin null")
        if config.get("battery", {}).get("enabled", False) is not False:
            raise ValueError("s2-demo has no battery ADC; battery.enabled must be false")
        if config.get("transport", "direct") not in ("direct", "gateway"):
            raise ValueError("s2-demo requires direct or gateway transport")
    else:
        raise ValueError("unknown hardware_profile")
    channels = config.get("channels", [])
    if not 1 <= len(channels) <= 2:
        raise ValueError("configure one or two channels")
    pins = []
    for channel in channels:
        validate_channel(channel)
        pins.append(channel["pin"])
    if len(set(pins)) != len(pins) or 15 in pins:
        raise ValueError("GPIO assignments overlap or use reserved GP15")
    if profile == "aa-demo" and any(pin not in (16, 17) for pin in pins):
        raise ValueError("aa-demo servo signals use GP16 or GP17")
    if profile == "s2-demo" and pins != [16]:
        raise ValueError("s2-demo requires exactly one servo signal on GPIO16")
    return enable_pin


class Controller:
    def __init__(self, config, hardware, sleep=None, persist=None, now=None):
        self.config = config
        self.hardware = hardware
        self.power_enable_pin = validate_hardware_config(config)
        self.channels = config.get("channels", [])
        self.lock = asyncio.Lock()
        self.sleep = sleep or asyncio.sleep
        self.states = ["unknown"] * len(self.channels)
        self.last_commands = [None] * len(self.channels)
        self.busy = False
        self.calibration = None
        self.calibration_revision = 0
        self.persist = persist
        self.now = now or (lambda: time.ticks_ms() if hasattr(time, "ticks_ms") else int(time.monotonic() * 1000))

    def calibration_status(self):
        draft = self.calibration
        if draft is not None:
            elapsed = (time.ticks_diff(self.now(), draft["updated_ms"]) if hasattr(time, "ticks_diff")
                       else self.now() - draft["updated_ms"])
            if elapsed >= 120000 and not self.busy:
                self.calibration = None
                return None
            return {"channel": draft["channel"], "revision": self.calibration_revision,
                    "values": {key: draft["cfg"][key + "_us"] for key in ("neutral", "off", "on")},
                    "tested": draft["tested"], "expires_in_s": max(0, (120000 - elapsed) // 1000)}
        return None
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

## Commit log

2026-09-05 feat: add Pico switch actuator prototype with CAD and local relay
    [1g_chassis.stl, 1g_electronics_lid.stl, 1g_fit_ring.stl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]
2026-09-05 feat(hardware): specify components and revise modular enclosure
    [1g_chassis.stl, 1g_electronics_lid.stl, 1g_servo1_yoke.stl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]
2026-09-05 feat(learn): add circuit course and headerless hardware BOM
    [auto-switch.blend, bom.csv, coupon_pico_mount.stl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]
2026-09-05 fix(diagram): draw the complete circuit as one connected map
    [app.js, continuous_wiring.py, render_wiring.py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]
2026-09-05 feat(learn): add checked breadboard layout and guided bench build
    [breadboard-placements.csv, placements.csv]
2026-09-05 feat(hardware): add AA demo BOM and illustrated breadboard
    [aa-demo-bom.csv, bom.csv, placements-1-servo.csv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]
2026-09-05 fix(hardware): scope current AA demo to one servo
    [aa-demo-bom.csv, bom.csv]
2026-09-06 docs(hardware): price the one-servo AA demo BOM
2026-09-06 docs(hardware): define switched-AA breadboard POC
2026-09-06 feat: add S2 AA breadboard map and Blender mounting prototype
    [01_plate_fit_ring.stl, 02_wall_chassis.stl, 03_factory_horn_paddle.stl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]
2026-09-06 feat: isolate servo actuator with Command strip mounting pads
    [01_plate_and_strip_fit_test.stl, 02_servo_mount.stl, 03_factory_horn_paddle.stl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]
2026-09-06 feat: export approved servo actuator print layout to STL
    [02_servo_mount.stl, 03_factory_horn_paddle.stl, print-layout-exported.blend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]
2026-09-06 chore: protect private configuration and block staged secrets
2026-09-06 feat: allow opt-in keyless LAN prototype control
2026-09-06 feat: simplify switch UI to mode interval and on-off controls
2026-09-06 feat: host minimal open demo UI directly on ESP32
2026-09-06 fix: audit BOM and revise electronics carrier fit-test geometry
    [electronics-carrier-v2.blend, electronics_carrier_v2_DRAFT_FIT_TEST.stl, full-assembly-review.blend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]
2026-09-06 docs: simplify project guides around the current S2 proof of concept
2026-09-06 feat: model screw mounts and removable electronics retention
    [electronics-retention-v3.blend, s2-current-bom.csv]
2026-09-06 feat: export reviewed v3 concept STL parts
    [01_carrier_base_CONCEPT.stl, 02_battery_bar_1_CONCEPT.stl, 03_battery_bar_2_CONCEPT.stl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]
2026-09-06 feat: add neutral calibration and combined electronics STL layouts
    [electronics-wall-mount-ASSEMBLED-CONCEPT.stl, electronics-wall-mount-all-pieces-CONCEPT.stl]
2026-09-06 feat: split electronics carrier from Command-strip wall bracket
    [01_carrier_base_CONCEPT.stl, 02_battery_bar_1_CONCEPT.stl, 03_battery_bar_2_CONCEPT.stl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]
2026-09-06 feat: add double and triple switch mechanical concepts
    [01_frame.stl, 02_saddle.stl, 03_saddle.stl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]
2026-09-06 feat: prototype recessed servo horn seat and fit coupons
    [horn-fit-coupon-clearance-0.2mm-PROVISIONAL.stl, horn-fit-coupon-clearance-0.3mm-PROVISIONAL.stl, horn-fit-coupon-clearance-0.4mm-PROVISIONAL.stl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]
2026-09-06 fix: keep switch state unknown after momentary presses
    [control.py, test_firmware.py]
2026-09-06 feat: fit tapered horn pocket to photo-based dimensions
    [horn-fit-coupon-clearance-0.2mm-PROVISIONAL.stl, horn-fit-coupon-clearance-0.3mm-PROVISIONAL.stl, horn-fit-coupon-clearance-0.4mm-PROVISIONAL.stl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]
2026-09-07 fix: replace battery crossbars with adjustable switch-clear retainers
    [01_LEFT_fixed_battery_edge_rail.stl, 02_LEFT_captured_pressure_shoe.stl, 03_RIGHT_fixed_battery_edge_rail.stl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]
2026-09-07 feat: simplify battery retention to a single crossbar preview
    [battery-retention-v6-SINGLE-CROSSBAR-PREVIEW.stl, battery-retention-v6-assembly-PREVIEW.blend, battery-retention-v6-print-PREVIEW.blend]
2026-09-07 fix(cad): center battery towers and seat flat bar on case
    [01_NEW-CARRIER-v7.stl, 02_FLAT-CROSSBAR-v7.stl, battery-retention-v7-NEW-CARRIER-AND-BAR.stl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]
2026-09-07 docs(cad): explore retention for received XL63070 module
    [booster-retention-options-PROVISIONAL.blend]
2026-09-07 feat(cad): export combined revision fit-test print set
    [01_01_NEW-CARRIER-v7.stl, 01_adapter-FIT-TEST.stl, 02_02_FLAT-CROSSBAR-v7.stl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]
2026-09-07 docs(wiring): map received board solder pads and review demo circuit
2026-09-08 docs: critically review minimal wiring and USB test modes
